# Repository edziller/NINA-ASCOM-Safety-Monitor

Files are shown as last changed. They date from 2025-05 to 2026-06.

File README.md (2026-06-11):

# Ziller Safety Monitor — NINA ASCOM Safety Monitor

Estação meteorológica remota baseada em **ESP8266** integrada ao software de astrofotografia **NINA** por meio de um **driver ASCOM Safety Monitor** totalmente funcional.

> Desenvolvido por Eduardo Ziller — Belo Horizonte, Brasil  
> Instagram: [@eduardoziller](https://instagram.com/eduardoziller) · YouTube: [Astronoziller](https://youtube.com/@astronoziller)

---

## 🔧 Visão geral

- **Firmware**: roda no ESP8266 (NodeMCU) e coleta dados de sensores ambientais em tempo real
- **Driver ASCOM**: desenvolvido em C# para comunicação via porta serial com o ESP, reportando `SAFE/UNSAFE` ao NINA
- **PCB dedicada**: duas placas projetadas no EasyEDA (PCB ESP 50×70mm + PCB Sensores 40×45mm)
- **Compatível com ASCOM Platform 6.6 ou superior**

---

## 📡 Sensores suportados

| Sensor | Função | Interface |
|---|---|---|
| MLX90614 | Temperatura IR do fundo do céu (detecção de nuvens) | I²C |
| BME280 *(v5 — recomendado)* | Temperatura, umidade e pressão | I²C |
| HTU21D *(v4)* | Temperatura e umidade | I²C |
| BMP280 *(v4)* | Pressão atmosférica | I²C |
| DHT11 *(v4-DHT — legado)* | Temperatura e umidade | 1-Wire |
| Sensor resistivo de chuva | Detecção de precipitação | Analógico |

---

## 🌦️ Lógica de segurança

O firmware avalia continuamente as leituras e determina `SAFE` ou `UNSAFE` com base em:

1. **Chuva detectada** → UNSAFE imediato
2. **Céu nublado + umidade alta + pressão baixa** → UNSAFE imediato  
3. **Céu nublado + umidade alta por tempo > Timeout** → UNSAFE
4. **Falha de sensor** → UNSAFE (comportamento fail-safe)

O sistema mantém `UNSAFE` até que **todas** as variáveis estejam seguras simultaneamente.

---

## 🗂️ Estrutura do projeto

```
.
├── Firmware/
│   ├── NINA-ASCOM-Safety-Monitor_v4-DHT.ino   # DHT11 + BMP280 + MLX90614
│   ├── NINA-ASCOM-Safety-Monitor_v4-HTU.ino   # HTU21D + BMP280 + MLX90614
│   └── NINA-ASCOM-Safety-Monitor_v5-BME.ino   # BME280 + MLX90614 (recomendado)
│
├── Driver/
│   ├── ZillerSafetyMonitor.sln
│   ├── ZillerSafetyMonitor/
│   │   ├── SafetyMonitorDriver.cs
│   │   ├── SafetyMonitorHardware.cs
│   │   ├── MonitorForm.cs / .Designer.cs
│   │   ├── SetupDialogForm.cs / .Designer.cs
│   │   └── FormOpcoesWifi.cs / .Designer.cs
│   └── Installer/
│       ├── Ziller_Safety_Monitor_Setup.iss
│       └── license.txt
│
├── PCB/
│   ├── Gerbers_PCB_ESP_50x70/
│   └── Gerbers_PCB_Sensores_40x45/
│
└── README.md
```

---

## 🔌 Hardware — PCBs

### PCB Sensores (40×45mm)
Contém os módulos de sensores I²C + componentes de proteção:

| Componente | Valor | Função |
|---|---|---|
| R1, R2 | 2.2kΩ 0402 | Pull-up SDA e SCL |
| C1 | 100nF X7R 0402 | Decoupling MLX90614 VDD |
| C2 | 10µF SMD | Bulk MLX90614 VDD |
| C3 | 100nF X7R 0402 | Filtro A0 sensor de chuva |
| U3 | PRTR5V0U2X SOT363 | Proteção ESD SDA/SCL |
| H1-H4 | NPTH 2.2mm | Fixação mecânica |

### PCB ESP (50×70mm)
Contém o NodeMCU ESP8266 e conector inter-board (6 pinos JST):

```
Pinout do conector inter-board:
  Pin 1: GND
  Pin 2: SDA  (D2 / GPIO4)
  Pin 3: GND
  Pin 4: SCL  (D1 / GPIO5)
  Pin 5: VCC 3.3V
  Pin 6: ANALOG (sensor de chuva → A0)
```

### Configuração I²C recomendada
```cpp
Wire.setClock(25000);             // 25kHz — estável com cabo de 15-20cm
Wire.setClockStretchLimit(25000); // 25ms — aguarda MLX90614 converter
```

---

## 💻 Instalação do Firmware

### Pré-requisitos (Arduino IDE)

**Placa:** `esp8266 by ESP8266 Community` via Board Manager

**Bibliotecas** (Sketch → Gerenciar Bibliotecas):

Para **v5-BME** (recomendado):
```
Adafruit BME280 Library
Adafruit MLX90614 Library
ESPAsyncTCP
ESPAsyncWebServer
```

Para **v4-HTU**:
```
Adafruit HTU21DF Library
Adafruit BMP280 Library
Adafruit MLX90614 Library
ESPAsyncTCP
ESPAsyncWebServer
```

Para **v4-DHT** (legado):
```
DHTesp
Adafruit BMP280 Library
Adafruit MLX90614 Library
ESPAsyncTCP
ESPAsyncWebServer
```

### Gravação
1. Selecione a placa `NodeMCU 1.0 (ESP-12E Module)`
2. Baud rate: `115200`
3. Carregue o firmware
4. Configure o WiFi pelo botão "Opções Wi-Fi" no Monitor

---

## 🌐 Página web embarcada

Quando conectado ao WiFi, o ESP serve uma interface completa:

| Endereço | Conteúdo |
|---|---|
| `http://<IP>/` | Painel de leituras em tempo real + extremos do dia |
| `http://<IP>/espstatus` | Diagnóstico de memória, uptime e saúde dos sensores |
| `http://<IP>/i2clog` | Log de eventos de recuperação do barramento I²C |
| `http://<IP>/logs` | Logs diários em CSV |

---

## 🛡️ Recuperação automática do barramento I²C

O firmware implementa recuperação automática quando 2+ sensores falham simultaneamente:

1. **9 pulsos SCL** — libera sensor que trava SDA em nível baixo
2. **Condição STOP** — reseta máquina de estado do sensor
3. **Wire reinit** — reinicializa o master ESP8266 nos pinos corretos
4. **Reinit sensores** — reinicializa cada sensor individualmente
5. **Após 3 tentativas** — reinicia o ESP automaticamente

Todos os eventos são registrados em `/i2c_eventos.csv` com timestamp, sensor responsável e resultado.

---

## 🖥️ Instalação do Driver ASCOM

### Pré-requisitos
- Windows 10 ou superior
- [ASCOM Platform 6.6+](https://ascom-standards.org/Downloads/Index.htm)
- .NET Framework 4.8
- Driver USB-Serial CP210x ou CH340 (instalado com Arduino IDE)

### Instalação
1. Execute `ZillerSafetyMonitor_Setup_v2.0.exe` como Administrador
2. Aceite os termos de licença
3. Siga as instruções do assistente

### Configuração no NINA
1. Equipamentos → Safety Monitor → selecione `Ziller Safety Monitor`
2. Clique em ⚙️ Setup e configure:
   - Porta COM do ESP8266
   - Altitude do observatório (metros)
   - Limites de IR, chuva, umidade, pressão e timeout
3. Clique em Conectar

---

## 📊 Parâmetros calibráveis

| Parâmetro | Padrão | Descrição |
|---|---|---|
| Limite IR Céu | 8.0°C | T IR acima da qual o céu é nublado |
| Limite Chuva | 850 | Valor ADC abaixo do qual há chuva (0-1023) |
| Limite ΔP | 0.0 hPa | Queda de pressão considerada preocupante |
| Limite Umidade | 70% | Umidade acima da qual é considerada alta |
| Timeout Nublado | 10 min | Tempo nublado+úmido para UNSAFE |
| Altitude | — m | Altitude do observatório para pressão nominal |

---

## 📝 Histórico de versões

### v5-BME (atual — recomendado)
- BME280 substitui BMP280 + HTU21D — um único CI para T, U e P
- Apenas 2 dispositivos no barramento I²C (MLX + BME) — maior estabilidade
- Clock I²C 25kHz + stretch 25ms

### v4-HTU
- HTU21D substitui DHT11 — precisão ±0.3°C/±2% vs ±2°C/±5%
- Recuperação automática do barramento I²C
- Log de eventos I²C em arquivo
- Página `/i2clog` com histórico de falhas
- Extremos de temperatura e umidade do dia na página web
- Tendência suavizada (média de 6 amostras vs 15 min atrás)
- Thresholds de tendência por grandeza: P=1.5hPa, U=3%, IR=3°C

### v4-DHT
- Versão legado com DHT11 + BMP280 + MLX90614
- Atualizada com toda a infraestrutura de recuperação I²C da v4-HTU

### v2/v3
- Watchdog de hardware (wdtEnable)
- EEPROM com magic byte para defaults na primeira execução
- Validação NaN em todos os sensores
- Clock I²C 50kHz → 25kHz
- Scan WiFi assíncrono
- UI tema escuro com beacon SAFE/UNSAFE
- Instalador com tela de licença (Inno Setup 6)

---

## 📄 Licença

MIT License — veja [license.txt](Driver/Installer/license.txt) para detalhes.

© 2025 Eduardo Ziller — Belo Horizonte, Brasil

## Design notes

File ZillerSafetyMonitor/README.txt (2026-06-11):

Ziller Safety Monitor
Driver ASCOM para monitoramento meteorológico de observatório remoto
=====================================================================

Versão:      2.0
Desenvolvedor: Eduardo Ziller — Belo Horizonte, Brasil
GitHub:      https://github.com/edziller/NINA-ASCOM-Safety-Monitor
Instagram:   @eduardoziller
YouTube:     Astronoziller
Email:       eduardo.ziller@gmail.com

Compatível com: ASCOM Platform 6.6 ou superior / NINA 3.x ou superior

─────────────────────────────────────────────────────────────────────
DESCRIÇÃO
─────────────────────────────────────────────────────────────────────
O Ziller Safety Monitor é um driver ASCOM do tipo Safety Monitor
desenvolvido para proteger automaticamente observatórios astronômicos
remotos contra condições meteorológicas adversas.

O hardware é baseado em um microcontrolador ESP8266 (NodeMCU) com
duas PCBs dedicadas, conectado aos seguintes sensores:

  Versão v5-BME (recomendada):
    • MLX90614  — temperatura IR do fundo do céu (detecção de nuvens)
    • BME280    — temperatura, umidade e pressão atmosférica

  Versão v4-HTU:
    • MLX90614  — temperatura IR do fundo do céu
    • HTU21D    — temperatura e umidade relativa do ar
    • BMP280    — pressão atmosférica

  Versão v4-DHT (legado):
    • MLX90614  — temperatura IR do fundo do céu
    • DHT11     — temperatura e umidade (1-wire)
    • BMP280    — pressão atmosférica

  Todos os sensores:
    • Sensor analógico de chuva resistivo

O firmware processa continuamente as leituras e determina se a
condição é SAFE ou UNSAFE com base em três lógicas combinadas:

  1. Chuva detectada → UNSAFE imediato
  2. Céu nublado + umidade alta + pressão baixa → UNSAFE imediato
  3. Céu nublado + umidade alta por tempo > Timeout → UNSAFE

Comportamento fail-safe: qualquer falha de sensor força UNSAFE.
O sistema mantém UNSAFE até que todas as variáveis sejam seguras.

Quando UNSAFE, o NINA interrompe a sequência de captura, fecha o
teto do observatório e desliga os equipamentos automaticamente.

─────────────────────────────────────────────────────────────────────
NOVIDADES DA VERSÃO 2.0
─────────────────────────────────────────────────────────────────────
Hardware e firmware:
  • PCB dedicada em duas placas (ESP 50x70mm + Sensores 40x45mm)
    com pull-ups I²C, capacitores de desacoplamento e proteção ESD
  • Suporte ao BME280 (v5) — um único sensor para T, U e P,
    eliminando o DHT11/HTU21D e aumentando a estabilidade I²C
  • Recuperação automática do barramento I²C:
      - 9 pulsos SCL para liberar sensor travado
      - Reinicialização completa do Wire e dos sensores
      - Reinício automático do ESP após 3 tentativas sem sucesso
  • Clock I²C: 25 kHz + clock stretch limit de 25 ms
  • Log de eventos I²C em arquivo CSV com timestamp
  • Tendência suavizada: média de 6 amostras vs 15 min atrás
    (elimina falsas tendências por ruído de sensor)
  • Extremos de temperatura e umidade do dia na página web
  • Watchdog de hardware no ESP8266 (reinício automático em travamento)

Interface e driver:
  • UI tema escuro com beacon SAFE/UNSAFE em destaque
  • Estado do céu e chuva exibidos no card de status
  • Pressão nominal visível ao lado da pressão atual
  • Parâmetros calibráveis diretamente no Setup Dialog do ASCOM
  • Parâmetros persistidos via ASCOM Profile (sobrevivem reinicializações)

Página web embarcada (acessível pelo IP do ESP):
  /             → painel completo com extremos do dia
  /espstatus    → diagnóstico de memória, uptime e saúde dos sensores
  /i2clog       → log de eventos de recuperação I²C em tempo real
  /logs         → logs diários em CSV para download

Instalador:
  • Tela de aceite de licença (MIT)
  • Verificação automática do ASCOM Platform antes de instalar
  • Suporte a Português Brasileiro e Inglês
  • Registro COM automático pós-instalação

─────────────────────────────────────────────────────────────────────
INSTALAÇÃO DO DRIVER
─────────────────────────────────────────────────────────────────────
Pré-requisitos:
  • Windows 10 ou superior
  • ASCOM Platform 6.6 ou superior
    https://ascom-standards.org/Downloads/Index.htm
  • .NET Framework 4.8
  • Driver USB-Serial CP210x ou CH340
    (normalmente instalado junto com a Arduino IDE)

Instalação:
  1. Execute "ZillerSafetyMonitor_Setup_v2.0.exe" como Administrador
  2. Aceite os termos de licença (MIT)
  3. Siga as instruções do assistente de instalação
  4. O driver será registrado automaticamente no ASCOM

─────────────────────────────────────────────────────────────────────
INSTALAÇÃO DO FIRMWARE
─────────────────────────────────────────────────────────────────────
  1. Instale a Arduino IDE (https://arduino.cc)
  2. No Board Manager, adicione:
       URL: http://arduino.esp8266.com/stable/package_esp8266com_index.json
       Placa: "esp8266 by ESP8266 Community"

  3. Instale as bibliotecas (Sketch → Gerenciar Bibliotecas):

     Para v5-BME (recomendado):
       • Adafruit BME280 Library
       • Adafruit MLX90614 Library
       • ESPAsyncTCP
       • ESPAsyncWebServer

     Para v4-HTU:
       • Adafruit HTU21DF Library
       • Adafruit BMP280 Library
       • Adafruit MLX90614 Library
       • ESPAsyncTCP
       • ESPAsyncWebServer

  4. Abra o arquivo .ino da versão desejada
  5. Selecione: Tools → Board → NodeMCU 1.0 (ESP-12E Module)
  6. Selecione a porta COM correta
  7. Carregue o firmware (Upload)
  8. Use o botão "Opções Wi-Fi" no Monitor para configurar a rede WiFi

─────────────────────────────────────────────────────────────────────
CONFIGURAÇÃO INICIAL
─────────────────────────────────────────────────────────────────────
  1. No NINA → Equipamentos → Safety Monitor
     Selecione "Ziller Safety Monitor" e clique em ⚙️ Setup

  2. Configure os parâmetros:
       • Porta COM do ESP8266
       • Altitude do observatório em metros
       • Limite IR Céu: 8.0°C (padrão — ajuste conforme seu local)
       • Limite Chuva: 850 (padrão — valor ADC do sensor, 0-1023)
       • Limite ΔP: 0.0 hPa (padrão)
       • Limite Umidade: 70% (padrão)
       • Timeout Nublado: 10 minutos (padrão)

  3. Clique OK e depois em Conectar

  4. O Monitor abrirá com todas as leituras em tempo real
     Os parâmetros também podem ser ajustados no Monitor e
     enviados ao ESP em tempo real clicando em "Salvar"

─────────────────────────────────────────────────────────────────────
DIAGNÓSTICO
─────────────────────────────────────────────────────────────────────
Se o sistema apresentar instabilidade no barramento I²C:

  1. Acesse http://<IP-do-ESP>/i2clog para ver o histórico de falhas
  2. Acesse http://<IP-do-ESP>/espstatus para ver saúde geral
  3. Verifique a resistência de pull-up no barramento I²C:
       Medido de SDA/SCL para VCC com sensores desconectados
       Valor esperado: 1.0kΩ a 2.5kΩ para operação estável a 25kHz
  4. Verifique a tensão VCC nos sensores: deve estar entre 3.1V e 3.3V
  5. Inspecione visualmente as soldas dos componentes SMD da PCB

─────────────────────────────────────────────────────────────────────
SUPORTE
─────────────────────────────────────────────────────────────────────
  • Issues e sugestões:
    https://github.com/edziller/NINA-ASCOM-Safety-Monitor/issues
  • Fórum ASCOM:
    https://ascomtalk.groups.io/g/Help
  • ASCOM Standards:
    https://ascom-standards.org

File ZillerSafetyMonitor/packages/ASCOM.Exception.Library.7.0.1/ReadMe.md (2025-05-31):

# ASCOM.Exceptions
Package of ASCOM exception types that can be used in both .NET Framework and .NET 5 and later applications.

# Version History

***7.0.1***
* Added a new constructor to NotImplementedException to enable messages to be presented "as-is" without adding the text "is not implemented.".

***7.0.0***
* Production release with Platform 7 support.

***7.0.0-rc.24***
* First public release with Platform 7 support.

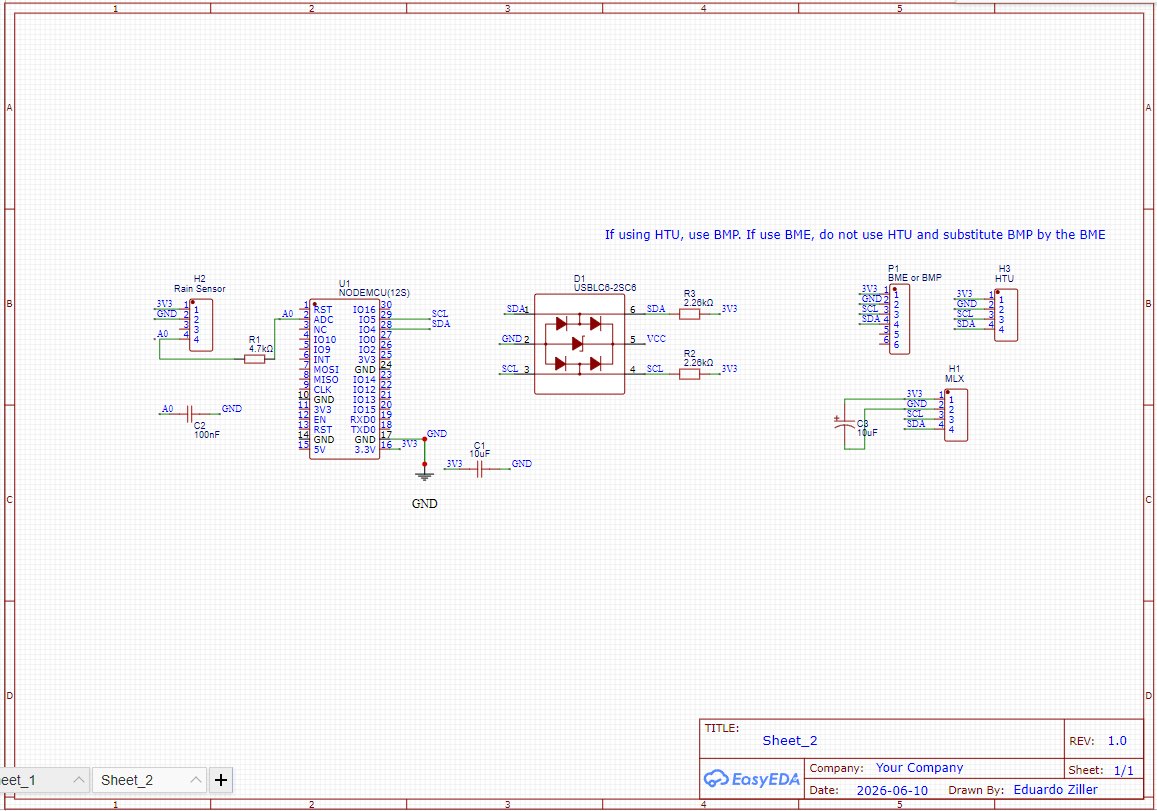
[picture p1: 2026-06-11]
Docs/schematics.png

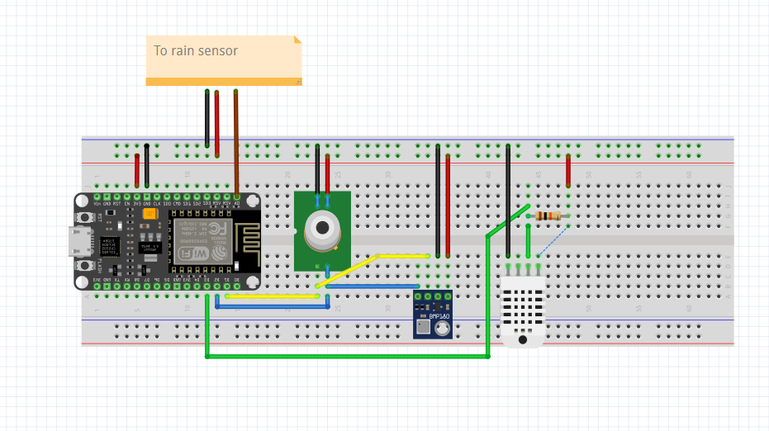
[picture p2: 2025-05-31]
esquematico_estacao_meteorologica.png

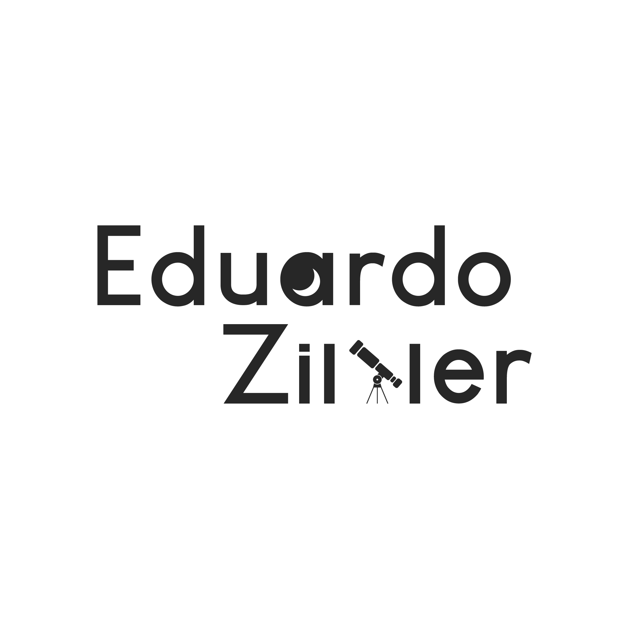
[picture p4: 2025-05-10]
ZillerSafetyMonitor/ZILLER.png

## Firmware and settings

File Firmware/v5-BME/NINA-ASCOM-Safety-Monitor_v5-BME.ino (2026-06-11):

// Ziller Safety Monitor
// Eduardo Ziller, Belo Horizonte, Brasil
// Entusiasta e astrônomo amador
// IG: @eduardoziller
//
// v5-BME — substituição de BMP280 + HTU21D pelo BME280 (sensor unico T/U/P):
//  - BME280 substitui BMP280 (pressao) e HTU21D (temp/umidade) em um unico CI
//  - Barramento I2C com apenas 2 sensores: MLX90614 (0x5A) + BME280 (0x76)
//  - Clock I2C: 50kHz — menos sensores = menos capacitancia = clock mais rapido
//  - Clock stretch: 25ms (adequado para MLX90614)
//  - BME280 em MODE_NORMAL — muito mais estavel que o BMP280
//  - Threshold de umidade: +-3% (BME280 preciso como o HTU21D)
//  - Recuperacao I2C automatica, log de eventos, watchdog HW mantidos


#include <Wire.h>

#include <Adafruit_MLX90614.h>
#include <Adafruit_BME280.h>
#include <ESP8266WiFi.h>
#include <ESPAsyncTCP.h>
#include <ESPAsyncWebServer.h>
#include <time.h>
#include <EEPROM.h>
#include <LittleFS.h>

Adafruit_MLX90614 mlx;

Adafruit_BME280   bme;
AsyncWebServer server(80);

// ── Pinos ─────────────────────────────────────────────────────────────────────
// HTU21D usa I²C (SDA/SCL) — sem pino dedicado
#define PIN_SENSOR_CHUVA     A0
#define PIN_SDA              4   // D2 — GPIO4
#define PIN_SCL              5   // D1 — GPIO5

// ── Recuperação I²C ───────────────────────────────────────────────────────────
// Se 2+ sensores falharem simultaneamente → barramento provavelmente travado
// Após MAX_TENTATIVAS_RESTART sem recuperar → reinicia o ESP
#define FALHAS_PARA_RECUPERAR    3   // falhas consecutivas por sensor
#define MAX_TENTATIVAS_RESTART   3   // reinicia rapido — melhor que ficar em loop   // reinicia após N tentativas sem sucesso

// ── Configurações gerais ──────────────────────────────────────────────────────
#define LOG_INTERVAL_MINUTES   5
#define WIFI_RECONNECT_INTERVAL 10000UL
#define NUMSAMPLES             20
#define TZ_OFFSET              (-3L * 3600L)
#define MIN_FREE_SPIFFS        51200
#define EEPROM_MAGIC_ADDR      12        // byte de controle de primeira execução
#define EEPROM_MAGIC_VALUE     0xAB      // valor arbitrário: "configurado"

// ── Janela de tendência (30 min / amostra a cada 5 s = 360 pontos) ────────────
#define TREND_WINDOW           360

// ── Thresholds de tendência por grandeza ──────────────────────────────────────
#define TREND_THRESH_P   1.5f   // hPa — limiar para tendência de pressão
#define TREND_THRESH_U   3.0f   // %   — HTU21D é estável, 3% já é tendência real
#define TREND_THRESH_IR  3.0f   // °C  — limiar para tendência de cobertura de nuvens

// ── Parâmetros do cálculo suavizado de tendência ──────────────────────────────
#define TREND_SMOOTH  6
#define TREND_LAG   180

// ── Histórico para tendências ─────────────────────────────────────────────────
float histPressure[TREND_WINDOW];
float histHumidity[TREND_WINDOW];
float histIR[TREND_WINDOW];
int   histIndex = 0;
bool  histInit  = false;

// ── Endereços EEPROM ──────────────────────────────────────────────────────────
const int ADDR_ALTITUDE       = 0;   // 2 bytes (uint16)
const int ADDR_LIM_IR         = 2;   // 2 bytes (uint16 = IR×10)
const int ADDR_LIM_CHUVA      = 4;   // 2 bytes (uint16)
const int ADDR_LIM_DELTA_P    = 6;   // 2 bytes (uint16 = ΔP×10 + offset 1000)
const int ADDR_LIM_UMIDADE    = 8;   // 2 bytes (uint16 = U×10)
const int ADDR_TIMEOUT_NUBLADO= 10;  // 2 bytes (uint16 = minutos)
// ADDR 12 = EEPROM_MAGIC_ADDR (byte único)

// ── Parâmetros calibráveis ────────────────────────────────────────────────────
struct Parametros {
  float    h;                  // altitude (m)
  int      limite_chuva;       // ex: 800  (valor bruto ADC; menor = mais molhado)
  float    limite_p;           // ex: -3.0 (ΔP mínimo em hPa)
  float    limite_u;           // ex: 75.0 (% umidade)
  float    limite_IR_ceu;      // ex: 2.0  (°C — IR acima disto = nublado)
  uint16_t timeout_nublado;    // minutos até UNSAFE por nublado persistente
} params;

// ── Leituras dos sensores (último valor válido) ───────────────────────────────
float u = 50.0f, t = 20.0f, to = 10.0f;
float p = 1013.25f, p_nominal = 1013.25f, delta_p = 0.0f;
float tIRceu = -10.0f;
int   media_sens_chuva = 1023;
int   condicaoSeguranca = 0;   // 0 = SAFE, != 0 = UNSAFE

// ── Contadores de falha por sensor ───────────────────────────────────────────
uint8_t falhasBME = 0, falhasMLX = 0;

// ── Contador de tentativas de recuperação I²C ─────────────────────────────────
uint8_t  tentativasRecuperacao  = 0;
uint16_t totalRecuperacoes      = 0;   // acumulado desde o boot
String   ultimaRecuperacaoHora  = "---";
String   sensoresNaUltimaFalha  = "---";

// ── Extremos do dia (resetados a meia-noite) ─────────────────────────────────
float tMax = -99.0f, tMin = 99.0f;
float uMax =   0.0f, uMin = 100.0f;
int   diaAtual = -1;

// ── Strings de estado ────────────────────────────────────────────────────────
String estado_chuva   = "Sem chuva";
String estado_nuvens  = "Céu limpo";
String pressaoStatus  = "Normal";
String trendPressao   = "---";
String trendUmidade   = "---";
String trendCeu       = "---";

// ── Temporização global ───────────────────────────────────────────────────────
unsigned long agora = 0, lastRead = 0, wifiLastCheck = 0;

// ── WiFi ──────────────────────────────────────────────────────────────────────
String ssid     = "";
String password = "";
bool   wifiCredenciaisCarregadas = false; 

// ── Scan WiFi assíncrono ──────────────────────────────────────────────────────
bool scanEmProgresso = false;

const char *stationName = "Estacao Meteorologica Observatorio Eureka";

// ─────────────────────────────────────────────────────────────────────────────
//  PARÂMETROS PADRÃO
// ─────────────────────────────────────────────────────────────────────────────
void setDefaultParameters() {
  params.h               = 0;
  params.limite_chuva    = 850;
  params.limite_p        = 0.0f;
  params.limite_u        = 70.0f;
  params.limite_IR_ceu   = 8.0f;
  params.timeout_nublado = 10;
}

// ─────────────────────────────────────────────────────────────────────────────
//  EEPROM
// ─────────────────────────────────────────────────────────────────────────────
void carregarParametrosEEPROM() {
  uint16_t a    = EEPROM.read(ADDR_ALTITUDE)        | (EEPROM.read(ADDR_ALTITUDE + 1)        << 8);
  params.h      = constrain((float)a, 0.0f, 10000.0f);

  uint16_t ir10 = EEPROM.read(ADDR_LIM_IR)          | (EEPROM.read(ADDR_LIM_IR + 1)          << 8);
  params.limite_IR_ceu = ir10 / 10.0f;

  uint16_t c    = EEPROM.read(ADDR_LIM_CHUVA)       | (EEPROM.read(ADDR_LIM_CHUVA + 1)       << 8);
  params.limite_chuva = (int)c;

  uint16_t dp10 = EEPROM.read(ADDR_LIM_DELTA_P)     | (EEPROM.read(ADDR_LIM_DELTA_P + 1)     << 8);
  params.limite_p = ((float)dp10 - 1000.0f) / 10.0f;

  uint16_t u10  = EEPROM.read(ADDR_LIM_UMIDADE)     | (EEPROM.read(ADDR_LIM_UMIDADE + 1)     << 8);
  params.limite_u = u10 / 10.0f;

  uint16_t tout = EEPROM.read(ADDR_TIMEOUT_NUBLADO) | (EEPROM.read(ADDR_TIMEOUT_NUBLADO + 1) << 8);
  params.timeout_nublado = tout;
}

void salvarParametrosEEPROM() {
  uint16_t a = (uint16_t)params.h;
  EEPROM.write(ADDR_ALTITUDE,     a & 0xFF);
  EEPROM.write(ADDR_ALTITUDE + 1, (a >> 8) & 0xFF);

  uint16_t ir10 = (uint16_t)(params.limite_IR_ceu * 10.0f);
  EEPROM.write(ADDR_LIM_IR,     ir10 & 0xFF);
  EEPROM.write(ADDR_LIM_IR + 1, (ir10 >> 8) & 0xFF);

  uint16_t c = (uint16_t)params.limite_chuva;
  EEPROM.write(ADDR_LIM_CHUVA,     c & 0xFF);
  EEPROM.write(ADDR_LIM_CHUVA + 1, (c >> 8) & 0xFF);

  uint16_t dp10 = (uint16_t)(params.limite_p * 10.0f + 1000.0f);
  EEPROM.write(ADDR_LIM_DELTA_P,     dp10 & 0xFF);
  EEPROM.write(ADDR_LIM_DELTA_P + 1, (dp10 >> 8) & 0xFF);

  uint16_t u10 = (uint16_t)(params.limite_u * 10.0f);
  EEPROM.write(ADDR_LIM_UMIDADE,     u10 & 0xFF);
  EEPROM.write(ADDR_LIM_UMIDADE + 1, (u10 >> 8) & 0xFF);

  uint16_t tout = params.timeout_nublado;
  EEPROM.write(ADDR_TIMEOUT_NUBLADO,     tout & 0xFF);
  EEPROM.write(ADDR_TIMEOUT_NUBLADO + 1, (tout >> 8) & 0xFF);

  EEPROM.commit();
}

// ─────────────────────────────────────────────────────────────────────────────
//  CREDENCIAIS WiFi (LittleFS)
// ─────────────────────────────────────────────────────────────────────────────
void salvarCredenciaisSPIFFS(const String &s, const String &senha) {
  File f = LittleFS.open("/wifi.txt", "w");
  if (!f) {
    Serial.println("Erro ao abrir arquivo de credenciais");
    return;
  }
  f.println(s);
  f.println(senha);
  f.close();
  Serial.println("Credenciais Wi-Fi salvas.");
}

void carregarCredenciaisWiFi() {
  File f = LittleFS.open("/wifi.txt", "r");
  if (!f) {
    Serial.println("Nenhuma credencial WiFi salva. Operando offline.");
    return;
  }
  ssid     = f.readStringUntil('\n'); ssid.trim();
  password = f.readStringUntil('\n'); password.trim();
  f.close();

  if (ssid.length() == 0) {
    Serial.println("SSID vazio no arquivo. Operando offline.");
    return;
  }

  WiFi.mode(WIFI_STA);
  WiFi.begin(ssid.c_str(), password.c_str());
  Serial.print("Conectando ao Wi-Fi");
  int result = WiFi.waitForConnectResult();
  Serial.println();

  if (result == WL_CONNECTED) {
    wifiCredenciaisCarregadas = true; 
    Serial.println("Wi-Fi conectado.");
    Serial.print("IP: ");
    Serial.println(WiFi.localIP());
  } else {
    // Credenciais existem mas não conectou agora → tenta depois no loop
    wifiCredenciaisCarregadas = true;   // credenciais são válidas para tentar de novo
    Serial.println("Nao foi possivel conectar. Tentara novamente em background.");
  }
}

// ─────────────────────────────────────────────────────────────────────────────
//  SETUP
// ─────────────────────────────────────────────────────────────────────────────
void setup() {
  delay(200);
  Serial.begin(115200);
  delay(100);

  // Watchdog de hardware do ESP8266 (8 segundos)
  ESP.wdtEnable(8000);

  EEPROM.begin(512);

  // Detecta primeira execução com magic byte
  if (EEPROM.read(EEPROM_MAGIC_ADDR) != EEPROM_MAGIC_VALUE) {
    Serial.println("Primeira execucao: gravando parametros padrao na EEPROM.");
    setDefaultParameters();
    salvarParametrosEEPROM();
    EEPROM.write(EEPROM_MAGIC_ADDR, EEPROM_MAGIC_VALUE);
    EEPROM.commit();
  } else {
    carregarParametrosEEPROM();
  }

  if (!LittleFS.begin()) {
    Serial.println("ERRO: falha ao montar LittleFS");
  } else {
    Serial.println("LittleFS montado.");
  }

  carregarCredenciaisWiFi();

  configTime(0, 0, "pool.ntp.org", "time.nist.gov");
  unsigned long tStart = millis();
  while (time(nullptr) < 24 * 3600 && millis() - tStart < 5000) {
    ESP.wdtFeed();
    delay(100);
  }

  // I2C a 25kHz + timeout de 25ms no clock stretch
  // setClockStretchLimit(25000): ESP desiste após 50ms se escravo não responder
  Wire.begin();
  Wire.setClock(50000);
  Wire.setClockStretchLimit(25000);
  Serial.println("Scan I2C:");
  for (byte addr = 1; addr < 127; addr++) {
    Wire.beginTransmission(addr);
    if (Wire.endTransmission() == 0) {
      Serial.print("  Encontrado: 0x");
      Serial.println(addr, HEX);
    }
  }

  // Inicializa sensores
  if (!mlx.begin()) {
    Serial.println("AVISO: MLX90614 nao encontrado. Verifique o I2C.");
  }
  // BME280 — substitui BMP280 + HTU21D (temperatura, umidade e pressao)
  // Endereco I2C: 0x76 (SDO=GND) ou 0x77 (SDO=VCC)
  if (!bme.begin(0x76)) {
    Serial.println("AVISO: BME280 nao encontrado. Verifique o I2C e o pino SDO.");
  } else {
    bme.setSampling(
      Adafruit_BME280::MODE_NORMAL,
      Adafruit_BME280::SAMPLING_X2,
      Adafruit_BME280::SAMPLING_X16,
      Adafruit_BME280::FILTER_X16,
      Adafruit_BME280::STANDBY_MS_500
    );
  }

  iniciarServidor();
  Serial.println("Ziller Safety Monitor iniciado.");
}

// ─────────────────────────────────────────────────────────────────────────────
//  LOOP PRINCIPAL
// ─────────────────────────────────────────────────────────────────────────────
void loop() {
  ESP.wdtFeed(); 

  handleLogging();
  agora = millis();
  tratarSerial();
  tratarScanWiFiAssincrono();

  if (agora - lastRead >= 5000) {
    lastRead = agora;
    lerSensores();
    calcularSeguranca();
  }

  if (wifiCredenciaisCarregadas
      && WiFi.status() != WL_CONNECTED
      && agora - wifiLastCheck > WIFI_RECONNECT_INTERVAL) {
    wifiLastCheck = agora;
    WiFi.disconnect();
    WiFi.begin(ssid.c_str(), password.c_str());
  }
}

// ─────────────────────────────────────────────────────────────────────────────
//  LOG DE EVENTOS I²C
// ─────────────────────────────────────────────────────────────────────────────
void logI2CEvento(uint8_t tentativa, bool reiniciando) {
  time_t tnow = time(nullptr) + TZ_OFFSET;
  struct tm ti;
  localtime_r(&tnow, &ti);
  char dateBuf[16], timeBuf[16];
  snprintf(dateBuf, sizeof(dateBuf), "%04d.%02d.%02d",
           ti.tm_year+1900, ti.tm_mon+1, ti.tm_mday);
  snprintf(timeBuf, sizeof(timeBuf), "%02d:%02d:%02d",
           ti.tm_hour, ti.tm_min, ti.tm_sec);

  File f = LittleFS.open("/i2c_eventos.csv", "a");
  if (!f) return;
  if (f.size() == 0)
    f.println("DATA,HORA,TENTATIVA,BME_FALHAS,MLX_FALHAS,SENSORES,RESULTADO");
  f.printf("%s,%s,%d,%d,%d,%s,%s\n",
    dateBuf, timeBuf, tentativa,
    falhasBME, falhasMLX,
    sensoresNaUltimaFalha.c_str(),
    reiniciando ? "RESTART_ESP" : "RECUPERADO");
  f.close();
}

// ─────────────────────────────────────────────────────────────────────────────
//  RECUPERAÇÃO DO BARRAMENTO I²C
//  Procedimento padrão SMBus:
//    1. 9 pulsos SCL  → libera escravo que trava SDA baixo
//    2. Condição STOP → reseta máquina de estado do escravo
//    3. Wire.end/begin → reinicializa master ESP8266
//    4. Reinit sensores
//    5. Após MAX_TENTATIVAS_RESTART falhas → ESP.restart()
// ─────────────────────────────────────────────────────────────────────────────
void recuperarI2C() {
  tentativasRecuperacao++;
  totalRecuperacoes++;

  // Registra quais sensores falharam e o horário
  String quem = "";
  if (falhasMLX >= FALHAS_PARA_RECUPERAR) quem += "MLX ";
  if (falhasBME >= FALHAS_PARA_RECUPERAR) quem += "BME";
  quem.trim();
  sensoresNaUltimaFalha = quem;

  time_t tnow = time(nullptr) + TZ_OFFSET;
  struct tm ti;
  localtime_r(&tnow, &ti);
  char timeBuf[12];
  snprintf(timeBuf, sizeof(timeBuf), "%02d:%02d:%02d",
           ti.tm_hour, ti.tm_min, ti.tm_sec);
  ultimaRecuperacaoHora = String(timeBuf);

  // ── Serial: mensagens detalhadas ─────────────────────────────────────────
  Serial.println();
  Serial.println("╔══════════════════════════════════════════════╗");
  Serial.printf( "║  [I2C] BARRAMENTO TRAVADO — Recuperacao #%d\n", tentativasRecuperacao);
  Serial.printf( "║  Hora: %s | Total desde boot: %d\n", timeBuf, totalRecuperacoes);
  Serial.printf( "║  Sensores falhando: %s\n", quem.c_str());
  Serial.printf( "║  Falhas: HTU=%d  MLX=%d  BMP=%d\n",
                 falhasBME, falhasMLX);
  Serial.println("╠══════════════════════════════════════════════╣");

  // Passo 1: 9 pulsos SCL
  yield(); // permite que o servidor web processe requests pendentes
  Serial.println("║  Passo 1: 9 pulsos SCL...");
  pinMode(PIN_SDA, INPUT_PULLUP);
  pinMode(PIN_SCL, OUTPUT);
  for (int i = 0; i < 9; i++) {
    digitalWrite(PIN_SCL, HIGH); delayMicroseconds(10);
    digitalWrite(PIN_SCL, LOW);  delayMicroseconds(10);
  }

  // Passo 2: Condição de STOP
  Serial.println("║  Passo 2: Condicao de STOP...");
  pinMode(PIN_SDA, OUTPUT);
  digitalWrite(PIN_SDA, LOW);  delayMicroseconds(10);
  digitalWrite(PIN_SCL, HIGH); delayMicroseconds(10);
  digitalWrite(PIN_SDA, HIGH); delayMicroseconds(10);

  // Passo 3: Reinicializa Wire
  Serial.println("║  Passo 3: Reinicializando Wire (50 kHz)...");
  // ESP8266: Wire.begin(sda,scl) forca reinicializacao correta dos pinos
  Wire.begin(PIN_SDA, PIN_SCL);
  Wire.setClock(50000);
  Wire.setClockStretchLimit(25000);
  delay(200);

  // Passo 4: Reinicializa sensores
  Serial.println("║  Passo 4: Reinicializando sensores...");
  bool mlxOk = mlx.begin();
  bool bmeOk = bme.begin(0x76);
  if (bmeOk) {
    bme.setSampling(Adafruit_BME280::MODE_NORMAL,
                    Adafruit_BME280::SAMPLING_X2,
                    Adafruit_BME280::SAMPLING_X16,
                    Adafruit_BME280::FILTER_X16,
                    Adafruit_BME280::STANDBY_MS_500);
  }
  Serial.printf("║  MLX=%s  BME=%s\n",
    mlxOk ? "OK" : "FALHOU",
    bmeOk ? "OK" : "FALHOU");

  // Zera contadores
  falhasMLX = 0; falhasBME = 0;

  // Verifica limite de tentativas
  yield(); // permite web server processar antes do possivel restart
  bool reiniciando = (tentativasRecuperacao >= MAX_TENTATIVAS_RESTART);

  // Grava no log antes de qualquer restart
  logI2CEvento(tentativasRecuperacao, reiniciando);

  if (reiniciando) {
    Serial.println("║  CRITICO: limite atingido — reiniciando ESP...");
    Serial.println("╚══════════════════════════════════════════════╝");
    delay(500);
    ESP.restart();
  }

  Serial.println("║  Recuperacao concluida. Aguardando proxima leitura...");
  Serial.println("╚══════════════════════════════════════════════╝");
  Serial.println();
}

// ─────────────────────────────────────────────────────────────────────────────
//  LEITURA DOS SENSORES  (com validação de NaN)
// ─────────────────────────────────────────────────────────────────────────────
void lerSensores() {
  // BME280: le temperatura, umidade e pressao de um unico sensor
  float novo_t = bme.readTemperature();
  float novo_u = bme.readHumidity();
  float novo_p = bme.readPressure() / 100.0f;

  bool bme_ok = !isnan(novo_t) && !isnan(novo_u) && !isnan(novo_p)
             && novo_u >= 0.0f && novo_u <= 100.0f
             && novo_p > 800.0f && novo_p < 1100.0f;

  if (bme_ok) {
    t = novo_t;
    u = novo_u;
    p = novo_p;
    falhasBME = 0;
  } else {
    falhasBME = min((int)falhasBME + 1, 255);
  }

  // MLX90614 — FIX: valida leitura
  float novo_ir = mlx.readObjectTempC();
  if (!isnan(novo_ir) && novo_ir > -40.0f && novo_ir < 85.0f) {
    tIRceu = novo_ir;
    falhasMLX = 0;
  } else {
    falhasMLX = min((int)falhasMLX + 1, 255);
    // Se o MLX falhar muitas vezes consecutivas, forçamos UNSAFE por precaução
    if (falhasMLX >= 3) {
      // Incapaz de avaliar o céu → conservativo: assume nublado
      tIRceu = params.limite_IR_ceu + 1.0f;
    }
  }

  // Inicializa buffers de histórico com o primeiro valor real
  if (!histInit) {
    for (int i = 0; i < TREND_WINDOW; i++) {
      histPressure[i] = p;
      histHumidity[i] = u;
      histIR[i]       = tIRceu;
    }
    histInit = true;
  }
  histIndex = (histIndex + 1) % TREND_WINDOW;
  histPressure[histIndex] = p;
  histHumidity[histIndex] = u;
  histIR[histIndex]       = tIRceu;

  float u_safe = constrain(u, 1.0f, 99.0f);
  float a_dew  = 17.27f, b_dew = 237.7f;
  float gamma  = (a_dew * t) / (b_dew + t) + log(u_safe / 100.0f);
  to = (b_dew * gamma) / (a_dew - gamma);

  // Pressão nominal pela fórmula barométrica 
  p_nominal = 1013.25f * exp(-0.0289644f * 9.81f * params.h / (8.31432f * (t + 273.15f)));
  delta_p   = p - p_nominal;

  // Atualiza maximos e minimos do dia (reset automatico a meia-noite)
  {
    time_t _tn = time(nullptr) + TZ_OFFSET;
    struct tm _td; localtime_r(&_tn, &_td);
    if (_td.tm_mday != diaAtual) {
      tMax = t; tMin = t; uMax = u; uMin = u;
      diaAtual = _td.tm_mday;
    }
    if (t > tMax) tMax = t;
    if (t < tMin) tMin = t;
    if (u > uMax) uMax = u;
    if (u < uMin) uMin = u;
  }

  // Sensor de chuva analógico — lê DEPOIS das transações I2C para evitar ruído
  int soma = 0;
  for (int i = 0; i < NUMSAMPLES; i++) {
    soma += analogRead(PIN_SENSOR_CHUVA);
    yield();
  }
  media_sens_chuva = soma / NUMSAMPLES;

  // ── Detecção e recuperação de travamento I²C ──────────────────────────────
  // Com 2 sensores: se ambos falharem simultaneamente = barramento travado
  int sensoresFalhando = (falhasMLX >= FALHAS_PARA_RECUPERAR ? 1 : 0)
                       + (falhasBME >= FALHAS_PARA_RECUPERAR ? 1 : 0);
  if (sensoresFalhando >= 2) {
    recuperarI2C();
  } else if (sensoresFalhando == 0) {
    tentativasRecuperacao = 0;
  }
}
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

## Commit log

2024-09-17 Add files via upload
    First upload
    - implementation of all sensors
2024-09-22 Update Estacao_meteorologica_observatorio.ino
    atualização com melhor logica da leitura do sensor de chuva, com filtro de tempo (sensor somente indica chuva caso fique molhado por mais de 3s)
2025-04-22 Update NINA-ASCOM-Safety-Monitor.ino
    Remoção de area duplicada do código
2025-05-10 Update NINA-ASCOM-Safety-Monitor.ino
    Código com condições de calculo de segurança ajustados e LOG gerado por hora contendo os dados meteorológicos medidos pela estação. Firmware pronto para comunicação SAFE/UNSAFE com o driver ASCOM
2025-05-10 Adicionados arquivos contendo o driver ASCOM
    Adicionados os arquivos contendo o driver ASCOM para o Ziller Safety Monitor, bem como o executavel para instalação.
2025-05-10 Update README.md
    Atualizado o readme do projeto contendo as ultimas atualizações. O esquematico ainda sera melhorado, pois contem erros de conexao.
2025-05-10 Update NINA-ASCOM-Safety-Monitor.ino
    Corrected constants values
    [NINA-ASCOM-Safety-Monitor.ino]
2025-06-17 Functional version with trends
    Added version of firmware with corrected safety conditions update
    [NINA-ASCOM-Safety-Monitor.ino]
2025-06-17 3D Files
    [base.stl, protecao_termica.stl, segmento1.stl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]
2025-08-10 Add files via upload
    .exe file with configuration for rain sensor threshold updated to 800 (was 890)
2026-03-05 Update NINA-ASCOM-Safety-Monitor.ino
    Changed delta P to -2 (was -3) and Sky background temperature up to 8 degrees C to consider clear sky
2026-04-09 Adiciona projeto completo com driver ASCOM e firmware
    # Conflicts:
    # NINA-ASCOM-Safety-Monitor.ino
    # Conflicts:
    # Firmware/NINA-ASCOM-Safety-Monitor/NINA-ASCOM-Safety-Monitor.ino
    # OLD/push_to_git.sh
    # README.md
    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
    [Cenarios Calculo Seguranca.xlsx, ZillerSafetyMonitor.fzz]
2026-06-11 docs: atualiza README.md com v5-BME, PCB v3, I2C recovery e histórico completo
2026-06-11 docs: adiciona esquematico logico das PCBs (EasyEDA)
2026-06-11 firmware: v4-DHT — DHT11+BMP280+MLX com recuperacao I2C automatica
2026-06-11 firmware: v4-HTU — HTU21D+BMP280+MLX com recuperacao I2C e extremos do dia
2026-06-11 firmware: v5-BME — BME280+MLX, 2 sensores I2C, versao recomendada
